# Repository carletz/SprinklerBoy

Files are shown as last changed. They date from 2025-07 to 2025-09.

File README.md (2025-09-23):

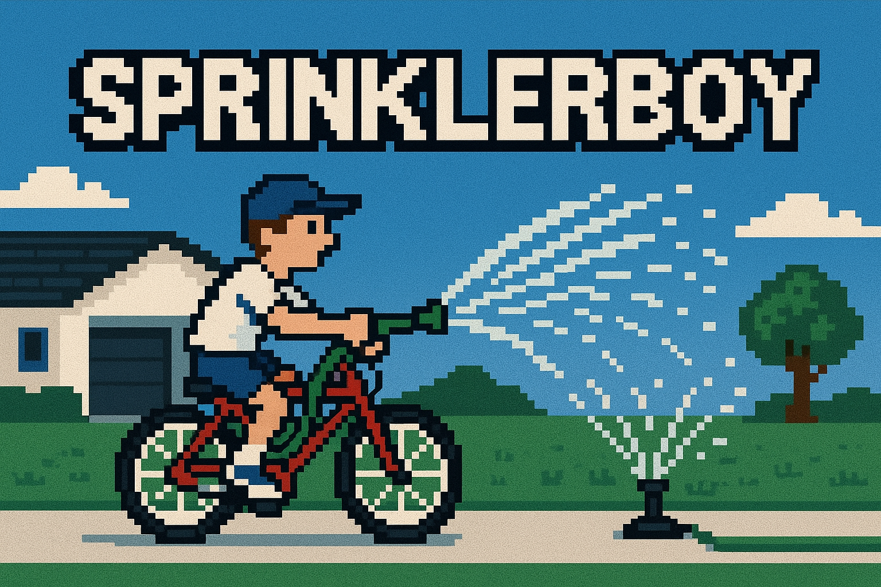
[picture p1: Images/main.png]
Render 1


# 🌿 SprinklerBoy – Take Full Control of Your Garden, the Smart Way

**SprinklerBoy** is your next-generation smart irrigation controller built around the powerful ESP32 and equipped with native Ethernet connectivity. Whether you're automating a home garden, greenhouse, or a professional irrigation system, SprinklerBoy delivers robust performance, high expandability, and complete control — right out of the box.

---

## 💡 Key Features

SprinklerBoy is a fully integrated, smart irrigation control system based on the **ESP32-WROOM-32UE** with native Ethernet **LAN8720A** support. Designed for reliable, flexible, and efficient irrigation, the project supports:

- Up to **8 AC-controlled sprinkler valves**
- Multiple **digital and analog inputs**
- **I2C-based expansion**
- **Robust surge protection**

### Main Hardware Features

- **ESP32 MCU**: Wi-Fi + Ethernet (LAN8720A PHY) with external antenna support  
- **8 Triac Outputs**: Control up to 8 AC sprinkler valves via opto-isolated TRIACs (MAC97A8)  
- **Input Protection**:  
  - Surge protection (SMBJ43CA)  
  - Flyback diodes (SS34)  
  - Fuses on both logic and power lines  
- **Multi-Input Capability**:  
  - 1 dry-contact input (e.g., rain sensor, external switches)  
  - 8 local physical push buttons  
  - 1 I2C analog keypad input (via ADS1115)  
  - I2C temperature and rain sensors  

### Communication Interfaces

- **Ethernet (LAN8720A)** with RJ45 magjack and status LEDs  
- **USB Type-C + CH340C** for programming and serial debug  
- **I2C bus** for additional peripherals and sensors  

### Power Supply

- Single **5V DC input** (external or USB-powered)  
- On-board **3.3V and 5V regulators** using LDO and switching converters (BL1117-33, XL1509)

### Modular Design

Four independent schematic blocks:

1. Controller Core (ESP32)  
2. Ethernet Interface  
3. Valve Output & Power Supply  
4. Input Interface Board  

> 🛠️ PCB ready: Designed in **EasyEDA** and optimized for **JLCPCB** assembly

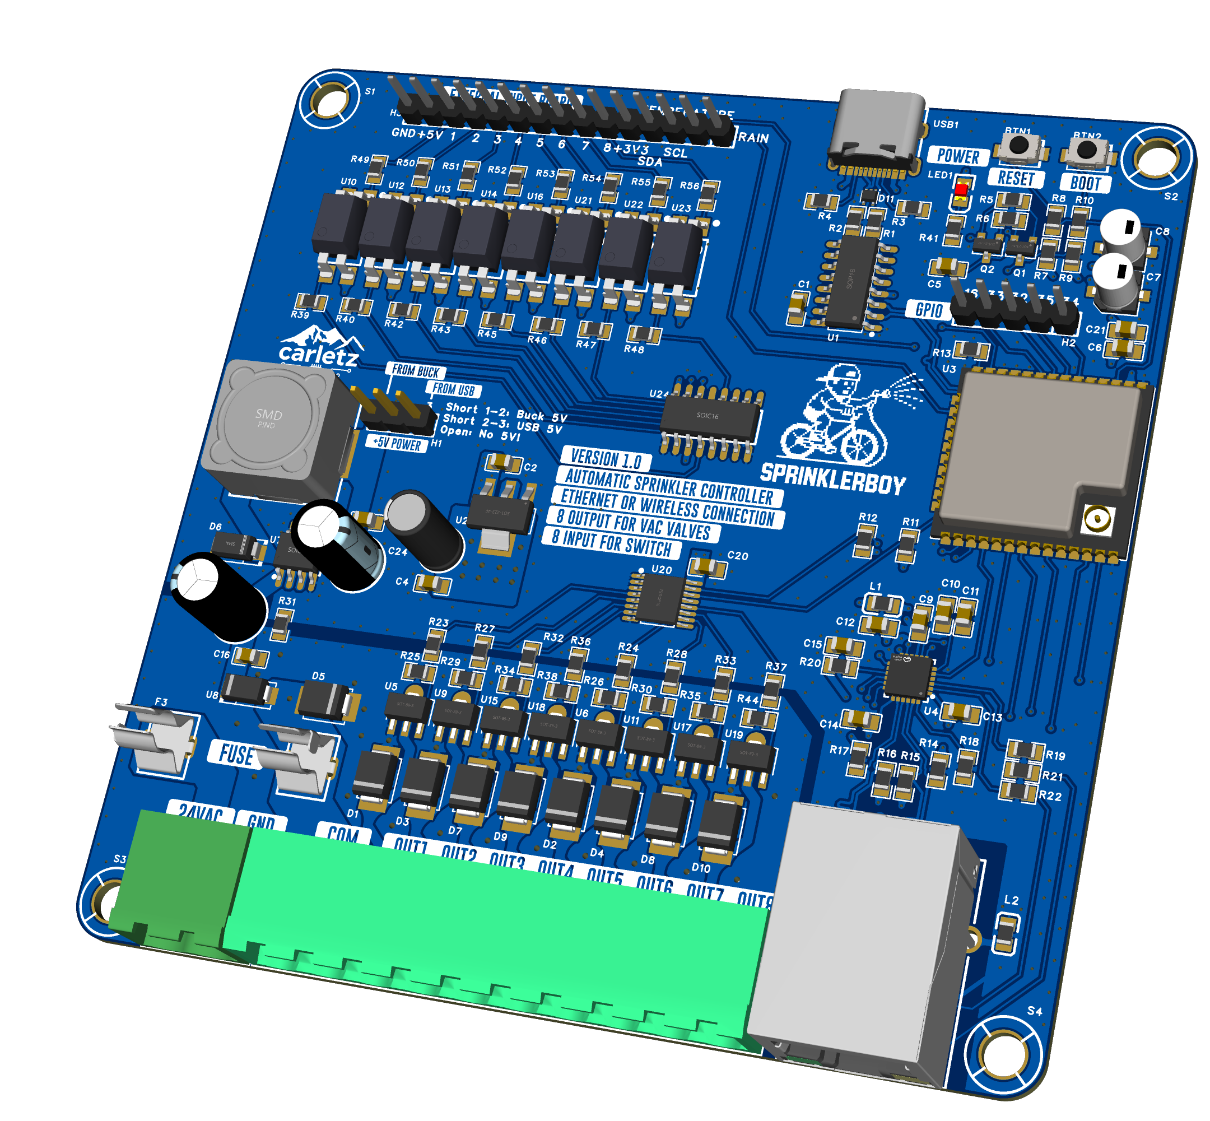
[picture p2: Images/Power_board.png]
Render 2


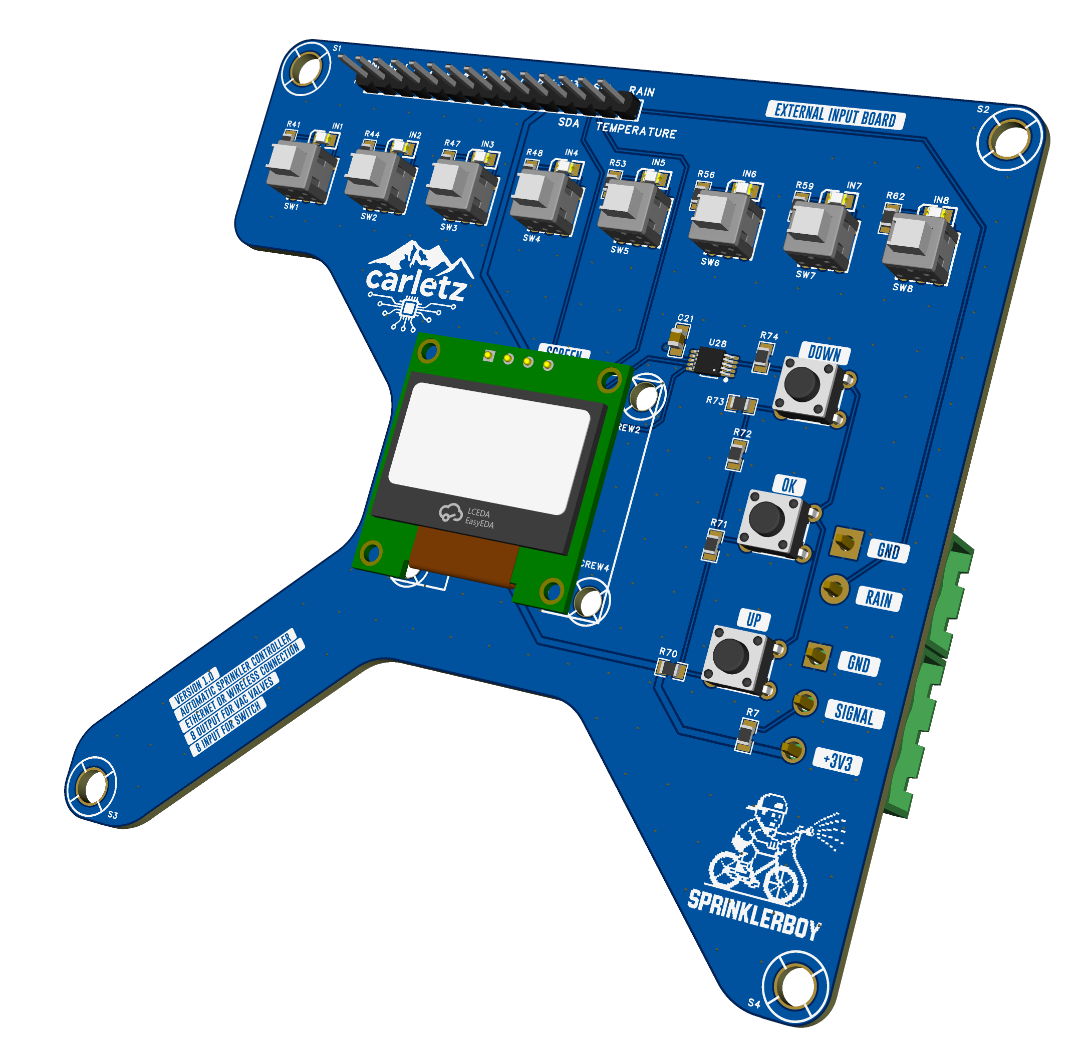
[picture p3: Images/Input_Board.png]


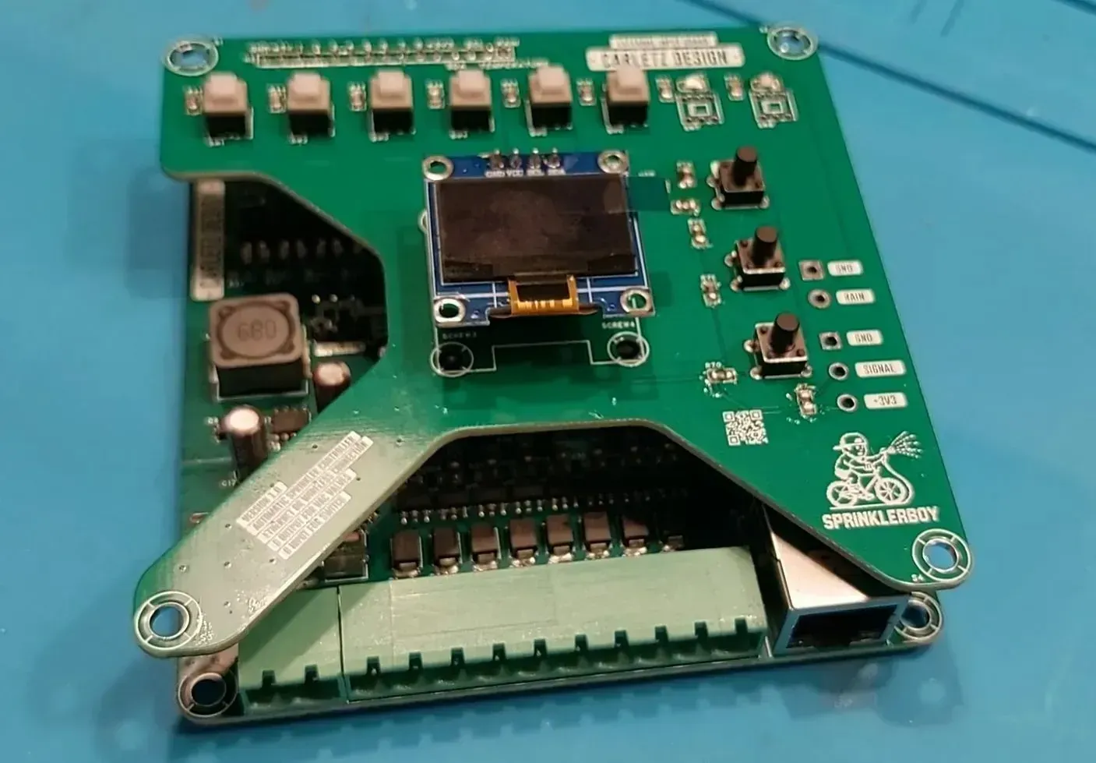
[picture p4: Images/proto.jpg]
Render 4


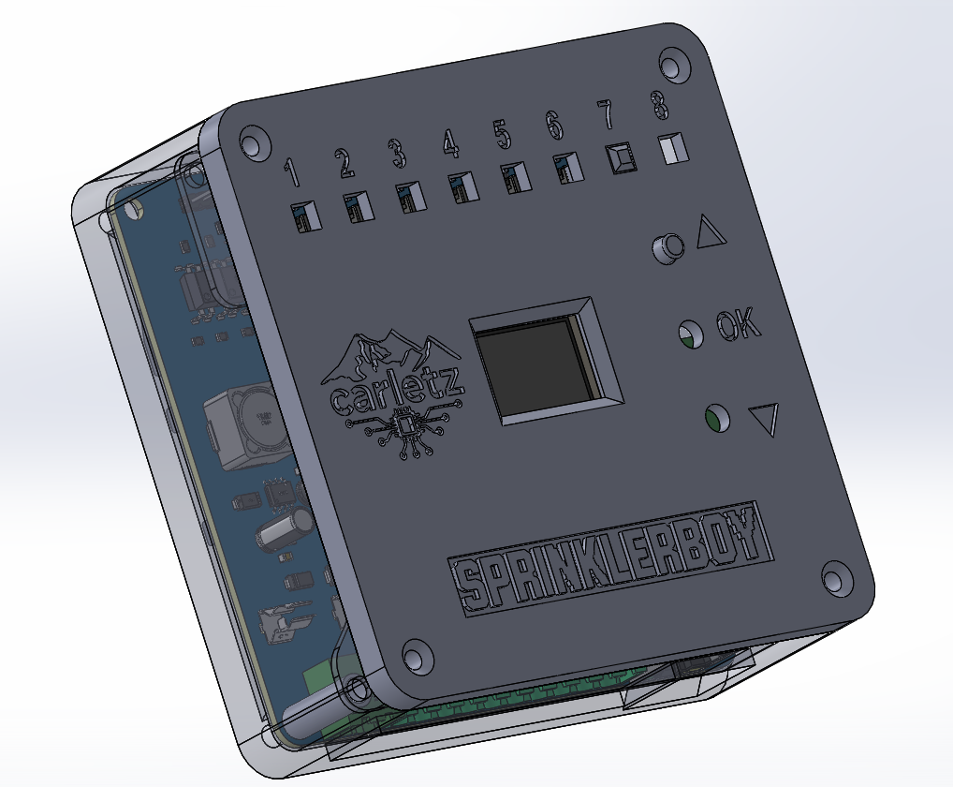
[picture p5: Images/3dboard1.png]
Render 5


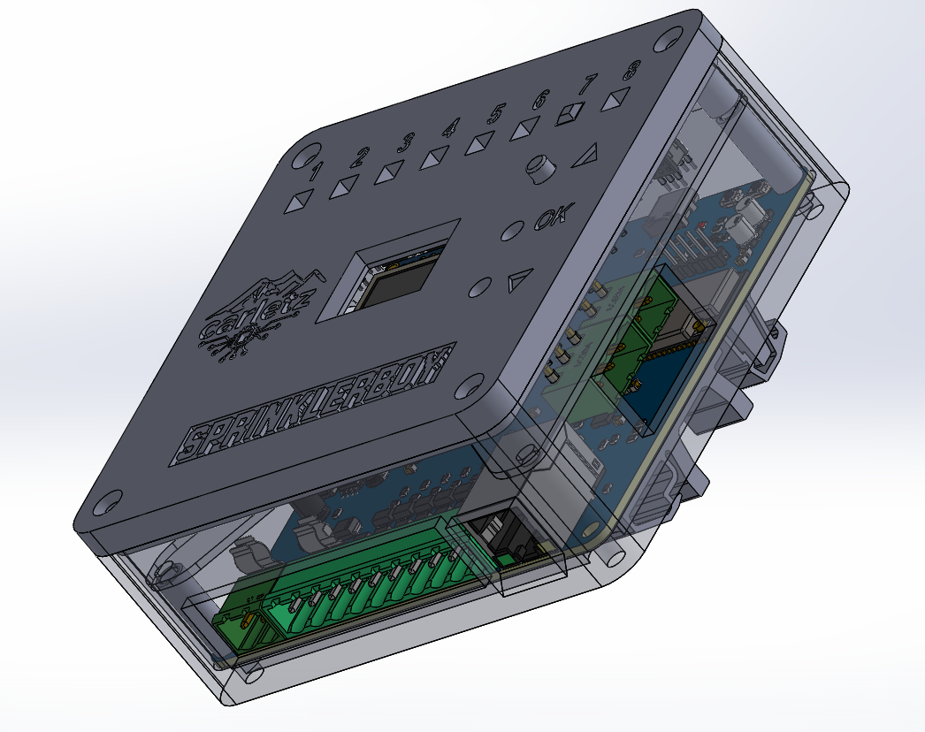
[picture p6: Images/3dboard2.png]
Render 6


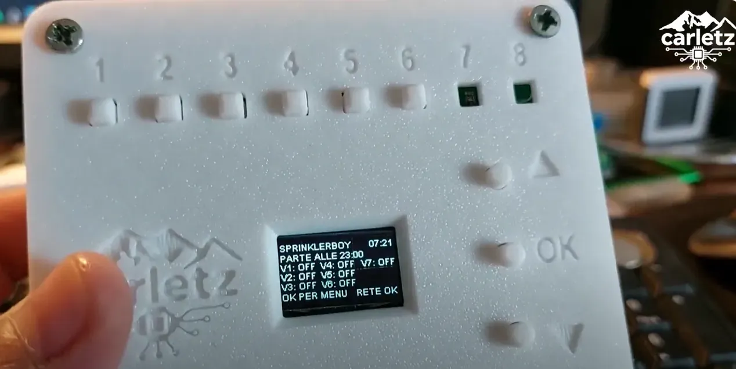
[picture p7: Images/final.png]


---

---
## 🎥 Construction Video

Watch the video (https://youtu.be/Xu3LNq0fTHU) 

---

## 🔧 Applications

- Home garden irrigation automation  
- Greenhouse or agricultural control systems  
- Integration with home automation platforms (via MQTT, HTTP, Modbus, etc.)

---

## ⚙️ Firmware Features – `sprinklerboy.yaml`

This **ESPHome-based** YAML configuration powers the SprinklerBoy smart irrigation controller, offering full integration with sensors, display, and networking.  
> The file given it's just an overall example, it have to be adapted to your needs.

---

## 🔌 Connectivity & Core

- ESP32 platform with:
  - Native Ethernet via `esp32_ethernet` using LAN8720  
  - Optional fallback Wi-Fi configuration  
- **MQTT Client**:
  - Publishes and subscribes to irrigation status, commands, schedules, and system variables  
  - Allows full control from platforms like **Home Assistant**, **OpenHAB**, or **Node-RED**

---

## 🌱 Irrigation Control

- **8 irrigation valves** controlled via GPIOs (mapped to hardware TRIACs)  
- **Automatic sequential irrigation**:
  - Configurable runtime per valve  
  - Optional skipping of disabled valves  
  - 5-second pause between valve changes  
- **Manual mode** via MQTT or physical button  
- **Weekly scheduler**:
  - Enable/disable irrigation per day (Mon–Sun)  
  - Each day configurable independently  

---

## 📟 User Interface

- **OLED Display** (SSD1306 128x64):
  - Real-time status updates (active valve, countdown, errors)  
  - Menu navigation using 3 physical buttons (UP, DOWN, OK)  
  - Inactivity timeout returns to standby screen showing:
    - Current time/date  
    - Connection status (ETH or fallback)  
    - Valve enable status summary  

### Menu System:

- Valve status toggle  
- Daily scheduling per valve  
- Irrigation enable/disable  
- Display mode toggle (active screen or standby)

---

## 🌧️ Sensor Inputs

- **Rain sensor** (digital, GPIO16):  
  When rain is detected, automatic irrigation is inhibited  

- **External temperature sensor** (via MQTT or physical):  
  Reserved for potential future logic (e.g., frost prevention)

---

## 🔘 Inputs

- 3 analog buttons via **ADS1115** (menu navigation)  
- 8 digital dry-contact inputs (opto-isolated):  
  - Usable for triggers, overrides, manual start, etc.

---

## 📤 MQTT Topics Overview

Includes topics for:

- Starting/stopping irrigation  
- Enabling/disabling individual valves  
- Scheduling per day  
- Reading back system status:
  - Active valve  
  - Remaining time  
  - Rain detection  
  - Connection status  
  - Errors  

---

## 🛡️ Safety & Logic

- Prevents irrigation when rain is detected  
- Watchdog logic to ensure no valve stays stuck  
- Auto-reset irrigation cycle in case of error  

---

## ⚠️ Disclaimer

> This project is provided for **educational purposes only**.

The author(s) of this repository **do not take any responsibility** for:

- Incorrect use of the design or schematics  
- Damage to equipment, persons, or property  
- Installation in unsafe or non-compliant environments  

Any implementation of this project in real-world systems should be done under the responsibility of a **qualified professional**, and in compliance with local regulations and safety standards.

By using this material, you acknowledge that it is offered **as-is**, **without warranty of any kind**, and you agree to use it **at your own risk**.

---

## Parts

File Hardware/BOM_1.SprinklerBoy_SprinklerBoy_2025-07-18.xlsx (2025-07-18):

No. | Quantity | Comment | Designator | Footprint | Value | Manufacturer Part | Manufacturer | Supplier Part | Supplier | LCSC Stock | LCSC Price | Primary Category | Secondary Category | Pin Count | JLCPCB Stock | JLCPCB Price | 3D Model Title | Device | Name | Unique ID | Convert to PCB | Add into BOM | Symbol | Layer | Mounting Style
1 | 2 | TS-1088-AR02016 | BTN1,BTN2 | SW-SMD_L3.9-W3.0-P4.45 |  | TS-1088-AR02016 | XUNPU(讯普) | C720477 | LCSC |  |  | Switches | Tactile Switches | 2 | 346433 | 0.0061 | SW-SMD_L3.9-W2.9-H2.0-LS4.8 | TS-1088-AR02016 | TS-1088-AR02016 | gge95_1,gge98_1 |  | yes |  | T | SMT
2 | 11 | 100nF | C1,C4,C11,C12,C13,C14,C15,C16,C19,C20,C21 | C0805 | 100nF | CL21B104KCFNNNE | SAMSUNG(三星) | C28233 | LCSC |  |  | Capacitors | Multilayer Ceramic Capacitors MLCC - SMD/SMT | 2 | 1168110 | 0.0009 | C0805_L2.0-W1.3-H1.3 | CL21B104KCFNNNE | 100nF | gge212,gge212_1,gge212_2,gge212_3,gge212_4,gge212_5,gge212_6,gge212_7,gge216,gge216_1,gge251 |  | yes |  | T | SMT
3 | 1 | 10uF | C2 | C0805 | 10uF | GRM21BR61H106KE43L | muRata(村田) | C440198 | LCSC |  |  | Capacitors | Multilayer Ceramic Capacitors MLCC - SMD/SMT | 2 | 1420512 | 0.0094 | C0805_L2.0-W1.3-H1.3 | GRM21BR61H106KE43L | 10uF | gge263 |  | yes |  | T | SMT
4 | 1 | 1uF | C5 | C0805 | 1uF | HHV0805R7105K101NSLJ | Chinocera(华瓷) | C22367837 | LCSC |  |  | Capacitors | Multilayer Ceramic Capacitors MLCC - SMD/SMT | 2 | 49911 | 0.0037 | C0805_L2.0-W1.3-H1.3 | HHV0805R7105K101NSLJ | 1uF | gge251_1 |  | yes |  | T | SMT
5 | 3 | 10uF | C6,C9,C10 | C0805 | 10uF | CL21A106KOQNNNE | SAMSUNG(三星) | C1713 | LCSC |  |  | Capacitors | Multilayer Ceramic Capacitors MLCC - SMD/SMT | 2 | 5303908 | 0.0013 | C0805_L2.0-W1.3-H1.3 | CL21A106KOQNNNE | 10uF | gge199,gge199_1,gge200 |  | yes |  | T | SMT
6 | 2 | 10uF | C7,C8 | CAP-SMD_BD4.0-L4.3-W4.3-LS5.1-FD | 10uF | VE-100M1ATR-0405 | lelon(立隆) | C249449 | LCSC |  |  | Capacitors | Aluminum Electrolytic Capacitors - SMD | 2 | 1 | 0.0083 | CAP-SMD_BD4.0-L4.3-W4.3-LS5.1-FD | VE-100M1ATR-0405 | 10uF | gge137_1,gge138_1 |  | yes |  | T | SMT
7 | 1 | 100uF | C22 | CAP-TH_BD5.0-P2.00-D0.5-FD-1 | 100uF | KM1A101M0507 | ROQANG(容强) | C2874000 | LCSC |  |  | Capacitors | Aluminum Electrolytic Capacitors - Leaded | 2 | 0 |  | CAP-TH_BD5.0-P2.00-D0.5-FD-1 | KM1A101M0507 | 100uF | gge304 |  | yes |  | T | DIP
8 | 2 | 100uF | C23,C24 | CAP-TH_BD6.3-P2.50-D1.0-FD | 100uF | GR107M050E12RR0VH4FP0 | CX(承兴) | C47891 | LCSC |  |  | Capacitors | Aluminum Electrolytic Capacitors - Leaded | 2 | 231035 | 0.005 | CAP-TH_BD6.3-P2.50-D1.0-FD | GR107M050E12RR0VH4FP0 | 100uF | gge305,gge306 |  | yes |  | T | DIP
9 | 1 | WJ2EDGRC-5.08-2P | CN1 | CONN-TH_2P-P5.08_WJ2EDGRC-5.08-2P |  | WJ2EDGRC-5.08-2P | KANGNEX(康奈克斯电气) | C3697 | LCSC |  |  | Connectors | Pluggable System Terminal Block | 2 | 22009 | 0.0053 | CONN-TH_2P-L12.0-W12.2-H8.3-P5.08 | WJ2EDGRC-5.08-2P | WJ2EDGRC-5.08-2P | gge35_1 |  | yes |  | T | DIP
10 | 1 | WJ2EDGRC-5.08-10P | CN2 | CONN-TH_10P-P5.08_WJ2EDGRC-5.08-10P |  | WJ2EDGRC-5.08-10P | KANGNEX(康奈克斯电气) | C28429 | LCSC |  |  | Connectors | Pluggable System Terminal Block | 10 | 126 | 0.0245 | CONN-TH_10P-P5.08_WJ2EDGRC-5.08-10P | WJ2EDGRC-5.08-10P | WJ2EDGRC-5.08-10P | gge312_1 |  | yes |  | T | DIP
11 | 9 | SMBJ43CA | D1,D2,D3,D4,D5,D7,D8,D9,D10 | SMB_L4.5-W3.6-LS5.3-BI |  | SMBJ43CA | GOODWORK(固得沃克) | C908858 | LCSC |  |  | TVS/Fuse/Board Level Protection | TVS | 2 | 8 | 0.0056 | SMB_L4.5-W3.6-LS5.3-RD | SMBJ43CA_C908858 | SMBJ43CA | gge2,gge2_1,gge5,gge5_1,gge8,gge8_1,gge11,gge11_1,gge36 |  | yes |  | T | SMT
12 | 1 | SS34 | D6 | SMA_L4.3-W2.5-LS5.0-RD |  | SS34 | TWGMC(台湾迪嘉) | C727060 | LCSC |  |  | Diodes | Schottky Barrier Diodes (SBD) | 2 | 274280 | 0.0037 | SMA_L4.3-W2.5-LS5.0-RD-1 | SS34_C727060 | SS34 | gge44 |  | yes |  | T | SMT
13 | 1 | TPD2E2U06DRLR | D11 | SOT-553-5_L1.6-W1.2-P0.50-LS1.6-TL-1 |  | TPD2E2U06DRLR | TI(德州仪器) | C1972959 | LCSC |  |  | Circuit Protection | ESD and Surge Protection (TVS/ESD) | 5 | 5981 | 0.0373 | SOT-553-5_L1.6-W1.2-P0.50-LS1.6-TL-1 | TPD2E2U06DRLR | TPD2E2U06DRLR | gge302 |  | yes |  | T | SMT
14 | 2 | 5x20 环保 保险管夹/座 | F2,F3 | FUSE-TH_5X20RHOSFUSECLIP-SEAT |  | 5x20 环保 保险管夹/座 | xcfuse(旭程) | C3130 | LCSC |  |  | TVS/Fuse/Board Level Protection | Fuse Holders | 2 | 52537 | 0.0029 | FUSE-TH_5X20 | 5x20 环保 保险管夹/座 | 5x20 环保 保险管夹/座 | gge33,gge34 |  | yes |  | T | DIP
15 | 1 | 77311-102-03LF | H1 | HDR-TH_3P-P2.54-V-M-1 |  | 77311-102-03LF | Amphenol | C180248 | LCSC |  |  | Connectors | Pin Headers | 3 | 4854 | 0.0256 | HDR-M-2.54_1x3 | 77311-102-03LF | 77311-102-03LF | UNIQUEH7 |  | yes |  | T | DIP
16 | 1 | HDR-M_2.54_1x5P | H2 | HDR-TH_5P-P2.54-V-M |  |  |  |  |  | 1334700 | 0.0057 | Connectors | Pin Headers | 5 |  |  | HDR-TH_5P-P2.54-M-LI-1X5P | HDR-M_2.54_1x5P |  | gge298 |  | yes |  | T | DIP
17 | 1 | HDR-M_2.54_1x15P | H3 | HDR-TH_15P-P2.54-V-M |  |  |  |  |  | 1334700 | 0.0057 | Connectors | Pin Headers | 15 |  |  | HDR-TH_15P-P2.54-M-LI-1X15P | HDR-M_2.54_1x15P |  | gge303 |  | yes |  | T | DIP
18 | 1 | HR911105A | J1 | RJ45-TH_HR911105A |  | HR911105A | HANRUN(汉仁) | C12074 | LCSC |  |  | Connectors | Ethernet Connectors/Modular Connectors (RJ45 RJ11) | 14 | 87630 | 0.2073 | RJ45-TH_P1HR911105A | HR911105A_C12074 | HR911105A | gge127_1 |  | yes |  | T | DIP
19 | 1 | BLM21PG220SN1D | L1 | L0805 |  | BLM21PG220SN1D | muRata(村田) | C88993 | LCSC |  |  | Filters | Ferrite Beads | 2 | 31886 | 0.0024 | R0805_L2.0-W1.3-H0.6 | BLM21PG220SN1D | BLM21PG220SN1D | gge132 |  | yes |  | T | SMT
20 | 1 | HCB2012KF-121T50 | L2 | L0805 |  | HCB2012KF-121T50 | TAI-TECH(台庆) | C304323 | LCSC |  |  | Filters | Ferrite Beads | 2 | 5086 | 0.0011 | R0805_L2.0-W1.3-H0.6 | HCB2012KF-121T50 | HCB2012KF-121T50 | gge242 |  | yes |  | T | SMT
21 | 1 | 68uH | L3 | IND-SMD_L12.3-W12.3_SMDRI127 | 68uH | SMDRI127-680MT | SXN(顺翔诺) | C9907 | LCSC |  |  | Inductors/Coils/Transformers | Power Inductors | 2 | 26241 | 0.0288 | SMD-PIND_L12.5-W12.5-H8.0 | SMDRI127-680MT | 68uH | gge45 |  | yes |  | T | SMT
22 | 1 | XL-2012SURC | LED1 | LED0805-R-RD |  | XL-2012SURC | XINGLIGHT(成兴光) | C965812 | LCSC |  |  | Optoelectronics | LED Indication - Discrete | 2 | 382647 | 0.0008 | LED0805-RD_RED_XL-2012SURC-FJ | XL-2012SURC | XL-2012SURC | gge156_10 |  | yes |  | T | SMT
23 | 2 | SS8050 | Q1,Q2 | SOT-23-3_L2.9-W1.3-P1.90-LS2.4-BR |  | SS8050 | JSMSEMI(杰盛微) | C916392 | LCSC |  |  | Transistors/Thyristors | Bipolar (BJT) | 3 | 814688 | 0.0011 | SOT-23-3P_L2.9-W1.3-H1.0-LS2.4-P0.95 | SS8050_C916392 | SS8050 | gge143,gge144 |  | yes |  | T | SMT
24 | 2 | 10Ω | R1,R2 | R0805_NEW | 10Ω | 0805W8F100JT5E | UNI-ROYAL(厚声) | C17415 | LCSC |  |  | Resistors | Chip Resistor - Surface Mount | 2 | 3278979 | 0.0003 | R0805_L2.0-W1.3-H0.6 | 0805W8F100JT5E | 10Ω | gge250,gge250_1 |  | yes |  | T | SMT
25 | 2 | 5.1kΩ | R3,R4 | R0805 | 5.1kΩ | RC0805FR-075K1L | YAGEO(国巨) | C84375 | LCSC |  |  | Resistors | Chip Resistor - Surface Mount | 2 | 100328 | 0.0003 | R0805_L2.0-W1.3-H0.6 | RC0805FR-075K1L | 5.1kΩ | gge300,gge301 |  | yes |  | T | SMT
26 | 2 | 12kΩ | R5,R6 | R0805 | 12kΩ | 0805W8J0123T5E | UNI-ROYAL(厚声) | C25616 | LCSC |  |  | Resistors | Chip Resistor - Surface Mount | 2 | 15966 | 0.0002 | R0805_L2.0-W1.3-H0.6 | 0805W8J0123T5E | 12kΩ | gge261,gge262 |  | yes |  | T | SMT
27 | 15 | 10kΩ | R7,R9,R11,R12,R13,R19,R20,R25,R26,R29,R30,R34,R35,R38,R44 | R0805 | 10kΩ | RC0805FR-7W10KL | YAGEO(国巨) | C17414 | LCSC |  |  | Resistors | Chip Resistor - Surface Mount | 2 | 12292545 | 0.0003 | R0805_L2.0-W1.3-H0.6 | RC0805FR-7W10KL | 10kΩ | gge204,gge204_1,gge204_5,gge204_6,gge204_7,gge204_8,gge204_9,gge204_10,gge204_11,gge204_12,gge221,gge221_1,gge225,gge225_1,gge225_2 |  | yes |  | T | SMT
28 | 2 | 100Ω | R8,R10 | R0805 | 100Ω | AC0805FR-7W100RL | YAGEO(国巨) | C727982 | LCSC |  |  | Resistors | Chip Resistor - Surface Mount | 2 | 3590 | 0.0012 | R0805_L2.0-W1.3-H0.6 | AC0805FR-7W100RL | 100Ω | gge252,gge253 |  | yes |  | T | SMT
29 | 4 | 49.9Ω | R14,R15,R16,R17 | R0805 | 49.9Ω | 0805W8F499JT5E | UNI-ROYAL(厚声) | C17720 | LCSC |  |  | Resistors | Chip Resistor - Surface Mount | 2 | 207272 | 0.0003 | R0805_L2.0-W1.3-H0.6 | 0805W8F499JT5E | 49.9Ω | gge238,gge238_1,gge238_2,gge238_3 |  | yes |  | T | SMT
30 | 1 | 12.1kΩ | R18 | R0805 | 12.1kΩ | 0805W8F1212T5E | UNI-ROYAL(厚声) | C17431 | LCSC |  |  | Resistors | Chip Resistor - Surface Mount | 2 | 9363 | 0.0003 | R0805_L2.0-W1.3-H0.6 | 0805W8F1212T5E | 12.1kΩ | gge254 |  | yes |  | T | SMT
31 | 2 | 510Ω | R21,R22 | R0805 | 510Ω | FRC0805J511 TS | FOJAN(富捷) | C2907333 | LCSC |  |  | Resistors | Chip Resistor - Surface Mount | 2 | 172084 | 0.0002 | R0805_L2.0-W1.3-H0.6 | FRC0805J511 TS | 510Ω | gge235,gge235_1 |  | yes |  | T | SMT
32 | 8 | 390Ω | R23,R24,R27,R28,R32,R33,R36,R37 | R0805 | 390Ω | 0805W8J0391T5E | UNI-ROYAL(厚声) | C25310 | LCSC |  |  | Resistors | Chip Resistor - Surface Mount | 2 | 22806 | 0.0003 | R0805_L2.0-W1.3-H0.6 | 0805W8J0391T5E | 390Ω | gge255,gge255_1,gge256,gge256_1,gge257,gge257_1,gge258,gge258_1 |  | yes |  | T | SMT
33 | 1 | 0Ω | R31 | R0805 | 0Ω | 0805W8F0000T5E | UNI-ROYAL(厚声) | C17477 | LCSC |  |  | Resistors | Chip Resistor - Surface Mount | 2 | 7785054 | 0.0003 | R0805_L2.0-W1.3-H0.6 | 0805W8F0000T5E_C17477 | 0Ω | gge240 |  | yes |  | T | SMT
34 | 8 | 1.43kΩ | R39,R40,R42,R43,R45,R46,R47,R48 | R0805 | 1.43kΩ | FRC0805F1431TS | FOJAN | C2933316 | LCSC |  |  | Resistors | Chip Resistor - Surface Mount | 2 | 5827 | 0.0003 | R0805_L2.0-W1.3-H0.6 | FRC0805F1431TS | 1.43kΩ | gge265,gge266,gge267,gge268,gge269,gge270,gge289,gge293 |  | yes |  | T | SMT
35 | 1 | 1kΩ | R41 | R0805 | 1kΩ | 0805W8F1001T5E | UNI-ROYAL(厚声) | C17513 | LCSC |  |  | Resistors | Chip Resistor - Surface Mount | 2 | 7426224 | 0.0003 | R0805_L2.0-W1.3-H0.6 | 0805W8F1001T5E | 1kΩ | gge254_1 |  | yes |  | T | SMT
36 | 8 | 1.33kΩ | R49,R50,R51,R52,R53,R54,R55,R56 | R0805 | 1.33kΩ | RC0805FR-071K33L | YAGEO(国巨) | C276298 | LCSC |  |  | Resistors | Chip Resistor - Surface Mount | 2 | 1749 | 0.0003 | R0805_L2.0-W1.3-H0.6 | RC0805FR-071K33L | 1.33kΩ | gge271,gge272,gge273,gge274,gge275,gge276,gge292,gge296 |  | yes |  | T | SMT
37 | 9 | PCB-SGAP | SP1,SP2,SP3,SP4,SP5,SP6,SP7,SP8,SP9 | AIR-GAP |  |  |  |  |  | 1334700 | 0.0057 |  |  | 2 |  |  |  | PCB-SGAP | PCB-SGAP | gge3,gge3_1,gge6,gge6_1,gge9,gge9_1,gge12,gge12_1,gge37 |  | yes |  | B | SMT
38 | 1 | CH340C | U1 | SOP-16_L10.0-W3.9-P1.27-LS6.0-BL |  | CH340C | WCH(南京沁恒) | C84681 | LCSC |  |  | Interface | USB Converters | 16 | 11967 | 0.0744 | SOP-16_L9.9-W3.9-H1.5-LS6.0-P1.27 | CH340C | CH340C | gge140 |  | yes |  | T | SMT
39 | 1 | BL1117-33CX | U2 | SOT-223-4_L6.5-W3.5-P2.30-LS7.0-BR |  | BL1117-33CX | BL(上海贝岭) | C5400 | LCSC |  |  | Power Management (PMIC) | Voltage Regulators - Linear, Low Drop Out (LDO) Regulators | 4 | 58592 | 0.0071 | SOT-223-4P_L6.5-W3.5-H1.6-LS7.0-P2.30 | BL1117-33CX | BL1117-33CX | gge46 |  | yes |  | T | SMT
40 | 1 | ESP32-WROOM-32UE-N8 | U3 | WIFI-SMD_ESP32-WROOM-32UE |  | ESP32-WROOM-32UE-N8 | ESPRESSIF(乐鑫) | C701345 | LCSC |  |  | IoT/Communication Modules | WiFi Modules | 47 | 2177 | 0.524 | WIFI-SMD_L19.2-18.0-H3.2-ESP32-WROOM-32UE | ESP32-WROOM-32UE-N8 | ESP32-WROOM-32UE-N8 | gge134 |  | yes |  | T | SMT
41 | 1 | LAN8720A-CP-TR-ABC | U4 | QFN-24_L4.0-W4.0-P0.50-TL-EP2.5 |  | LAN8720A-CP-TR-ABC | MICROCHIP(美国微芯) | C621419 | LCSC |  |  | Interface | Ethernet Transceivers | 25 | 1462 | 0.1477 | VFQFN-24_L4.0-W4.0-P0.50-TL-EP2.1 | LAN8720A-CP-TR-ABC | LAN8720A-CP-TR-ABC | gge131 |  | yes |  | T | SMT
42 | 8 | MAC97A8 | U5,U6,U9,U11,U15,U17,U18,U19 | SOT-89-3_L4.5-W2.5-P1.50-LS4.2-BR |  | MAC97A8 | MSKSEMI(美森科) | C5140027 | LCSC |  |  | Triode/MOS Tube/Transistor | TRIACs | 3 | 440 | 0.0108 | SOT-89-3_L4.3-W2.5-H1.6-LS4.1-P1.50 | MAC97A8_1 | MAC97A8 | gge1,gge1_1,gge4,gge4_1,gge7,gge7_1,gge10,gge10_1 |  | yes |  | T | SMT
43 | 1 | XL1509-5.0E1 | U7 | SOIC-8_L5.0-W4.0-P1.27-LS6.0-BL |  | XL1509-5.0E1 | XLSEMI(芯龙) | C61063 | LCSC |  |  | Power Supply Chip | DC-DC Converters | 8 | 428775 | 0.0317 | SOIC-8_L4.9-W3.9-H1.7-LS6.0-P1.27 | XL1509-5.0E1 | XL1509-5.0E1 | gge40 |  | yes |  | T | SMT
44 | 1 | M7 | U8 | SMA_L4.5-W2.7-LS5.1-RD |  | M7 | MSKSEMI(美森科) | C2902910 | LCSC |  |  | Diodes | Diodes - General Purpose | 2 | 1130935 | 0.0008 | SMA_L4.5-W2.7-LS5.1-RD | M7_C2902910 | M7 | gge43 |  | yes |  | T | SMT
45 | 8 | PC817AS | U10,U12,U13,U14,U16,U21,U22,U23 | SOP-4_L6.4-W4.6-P2.54-LS10.2-BL |  | PC817AS | AOTE(奥特) | C22375537 | LCSC |  |  | Optoisolators | Transistor, Photovoltaic Output Optoisolators | 4 | 1860 | 0.0065 | SOP-4_L6.5-W4.6-H4.5-P2.54-LS10.2-TL | PC817AS | PC817AS | gge147,gge152,gge156,gge160,gge164,gge168,gge168_1,gge168_2 |  | yes |  | T | SMT
46 | 1 | PCA9554APW,118 | U20 | TSSOP-16_L5.0-W4.4-P0.65-LS6.4-BL |  | PCA9554APW,118 | NXP(恩智浦) | C86803 | LCSC |  |  | Communication Interface Chip/UART/485/232 | I/O Expanders | 16 | 3050 | 0.1158 | TSSOP-16_L5.0-W4.4-H1.0-LS6.4-P0.65 | PCA9554APW,118 | PCA9554APW,118 | gge53 |  | yes |  | T | SMT
47 | 1 | PCF8574M/TR | U24 | SOIC-16_L9.9-W3.9-P1.27-LS6.0-BL-1 |  | PCF8574M/TR | HGSEMI(华冠) | C5310792 | LCSC |  |  | Interface | I/O Expanders | 16 | 1197 | 0.1035 | SOIC-16_L9.9-W3.9-H1.8-LS6.0-P1.27-EP13 | PCF8574M/TR | PCF8574M/TR | gge144_1 |  | yes |  | T | SMT
48 | 1 | TYPE-C 16PIN 2MD(073) | USB1 | USB-C-SMD_TYPE-C-6PIN-2MD-073 |  | TYPE-C 16PIN 2MD(073) | SHOU HAN(首韩) | C2765186 | LCSC |  |  | Connectors | USB Connectors | 16 | 444139 | 0.0081 | USB-C-SMD_TYPE-C-6PIN-2MD-073 | TYPE-C 16PIN 2MD(073) | TYPE-C 16PIN 2MD(073) | gge130_1 |  | yes |  | T | DIP

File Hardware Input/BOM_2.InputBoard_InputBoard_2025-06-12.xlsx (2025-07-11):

No. | Quantity | Comment | Designator | Footprint | Value | Manufacturer Part | Manufacturer | Supplier Part | Supplier | LCSC Stock | LCSC Price | Primary Category | Secondary Category | Pin Count | JLCPCB Stock | JLCPCB Price | 3D Model Title | Device | Name | Unique ID | Convert to PCB | Add into BOM | Symbol | Layer | Mounting Style
1 | 3 | KH-6X6X8H-TJ | ((DOWN)),((OK)),((UP)) | SW-TH_4P-L6.0-W6.0-P4.50-LS6.5 |  | KH-6X6X8H-TJ | kinghelm(金航标) | C2837518 | LCSC |  |  | Key/Switch | Tactile Switches | 4 | 4729 | 0.0021 | SW-TH_4P-L6.0-W6.0-H5.0-LS6.5-P4.50 | KH-6X6X8H-TJ | KH-6X6X8H-TJ | gge35_1,gge36_1,gge38 |  | yes |  | T | Straight
2 | 1 | 1uF | C21 | C0805 | 1uF | HHV0805R7105K101NSLJ | Chinocera(华瓷) | C22367837 | LCSC |  |  | Capacitors | Multilayer Ceramic Capacitors MLCC - SMD/SMT | 2 | 46397 | 0.0038 | C0805_L2.0-W1.3-H1.3 | HHV0805R7105K101NSLJ | 1uF | gge251_2 |  | yes |  | T
3 | 1 | WJ2EDGRC-5.08-3P | CN1 | CONN-TH_3P-P5.08_WJ2EDGRC-5.08-3P |  | WJ2EDGRC-5.08-3P | KANGNEX(康奈克斯电气) | C8377 | LCSC |  |  | Connectors | Pluggable System Terminal Block | 3 | 6038 | 0.0079 | CONN-TH_WJ5.08-WI-3P-4 | WJ2EDGRC-5.08-3P_C8377 | WJ2EDGRC-5.08-3P | gge50_1 |  | yes |  | B | Bend
4 | 1 | WJ2EDGRC-5.08-2P | CN2 | CONN-TH_2P-P5.08_WJ2EDGRC-5.08-2P |  | WJ2EDGRC-5.08-2P | KANGNEX(康奈克斯电气) | C3697 | LCSC |  |  | Connectors | Pluggable System Terminal Block | 2 | 16690 | 0.0053 | CONN-TH_2P-L12.0-W12.2-H8.3-P5.08 | WJ2EDGRC-5.08-2P | WJ2EDGRC-5.08-2P | gge35_2 |  | yes |  | B | Bend
5 | 1 | HDR-M_2.54_1x15P | H3 | HDR-TH_15P-P2.54-V-M |  |  |  |  |  | 690 | 0.1743 | Connectors | Pin Headers | 15 |  |  | HDR-TH_15P-P2.54-M-LI-1X15P | HDR-M_2.54_1x15P |  | gge303_1 |  | yes |  | T
6 | 8 | XL-2012SURC | IN1,IN2,IN3,IN4,IN5,IN6,IN7,IN8 | LED0805-R-RD |  | XL-2012SURC | XINGLIGHT(成兴光) | C965812 | LCSC |  |  | Optoelectronics | LED Indication - Discrete | 2 | 1044465 | 0.0008 | LED0805-RD | XL-2012SURC | XL-2012SURC | gge156_1,gge156_2,gge156_3,gge156_4,gge156_5,gge156_6,gge156_7,gge156_8 |  | yes |  | T
7 | 1 | 4.7kΩ | R7 | R0805 | 4.7kΩ | 0805W8F4701T5E | UNI-ROYAL(厚声) | C17673 | LCSC |  |  | Resistors | Chip Resistor - Surface Mount | 2 | 8008773 | 0.0003 | R0805_L2.0-W1.3-H0.6 | 0805W8F4701T5E | 4.7kΩ | gge246 |  | yes |  | T
8 | 8 | 220Ω | R41,R44,R47,R48,R53,R56,R59,R62 | R0805 | 220Ω | 0805W8F2200T5E | UNI-ROYAL(厚声) | C17557 | LCSC |  |  | Resistors | Chip Resistor - Surface Mount | 2 | 816371 | 0.0003 | R0805_L2.0-W1.3-H0.6 | 0805W8F2200T5E | 220Ω | gge277,gge278_1,gge279_2,gge279_3,gge281,gge282,gge291,gge295 |  | yes |  | T
9 | 4 | 1kΩ | R70,R71,R72,R73 | R0805 | 1kΩ | 0805W8F1001T5E | UNI-ROYAL(厚声) | C17513 | LCSC |  |  | Resistors | Chip Resistor - Surface Mount | 2 | 10341441 | 0.0003 | R0805_L2.0-W1.3-H0.6 | 0805W8F1001T5E | 1kΩ | gge305,gge306,gge307,gge308 |  | yes |  | T
10 | 1 | 1MΩ | R74 | R0805 | 1MΩ | 0805W8F1004T5E | UNI-ROYAL(厚声) | C17514 | LCSC |  |  | Resistors | Chip Resistor - Surface Mount | 2 | 1835631 | 0.0003 | R0805_L2.0-W1.3-H0.6 | 0805W8F1004T5E | 1MΩ | gge309 |  | yes |  | T
11 | 4 | Screw-Hole-M3 | SCREW1,SCREW2,SCREW3,SCREW4 | Screw-Hole-M3 |  |  |  |  |  | 690 | 0.1743 |  |  | 1 |  |  |  | Screw-Hole-M3 |  | $1,$2,$3,$4 |  | yes |  | T
12 | 8 | 5.8 ZSPT | SW1,SW2,SW3,SW4,SW5,SW6,SW7,SW8 | SW-TH_5.8ZSPT |  | 5.8 ZSPT | SHOU HAN(首韩) | C2681588 | LCSC |  |  | Switches | Pushbutton Switches | 6 | 15481 | 0.0128 | SW-TH_5.8ZSPT | 5.8 ZSPT | 5.8 ZSPT | gge278,gge278_2,gge278_3,gge278_4,gge278_5,gge278_6,gge278_7,gge278_8 |  | yes |  | T
13 | 1 | HS96L03W2C03 | U27 | OLED-TH_L27.8-W27.2-P2.54_C9900033791 |  | HS96L03W2C03 | HS(汉昇) | C5248080 | LCSC |  |  | Displays | OLED Display | 4 | 95 | 0.2816 | OLED-TH_L27.8-W27.2-P2.54_C9900033791 | HS96L03W2C03 | HS96L03W2C03 | gge304 |  | yes |  | T
14 | 1 | ADS1115IDGSR | U28 | MSOP-10_L3.0-W3.0-P0.50-LS5.0-BL |  | ADS1115IDGSR | TI(德州仪器) | C37593 | LCSC |  |  | Data Acquisition | Analog to Digital Converters (ADC) | 10 | 10239 | 0.1363 | MSOP-10_L3.0-W3.0-H1.1-LS5.0-P0.50 | ADS1115IDGSR | ADS1115IDGSR | gge190 |  | yes |  | T

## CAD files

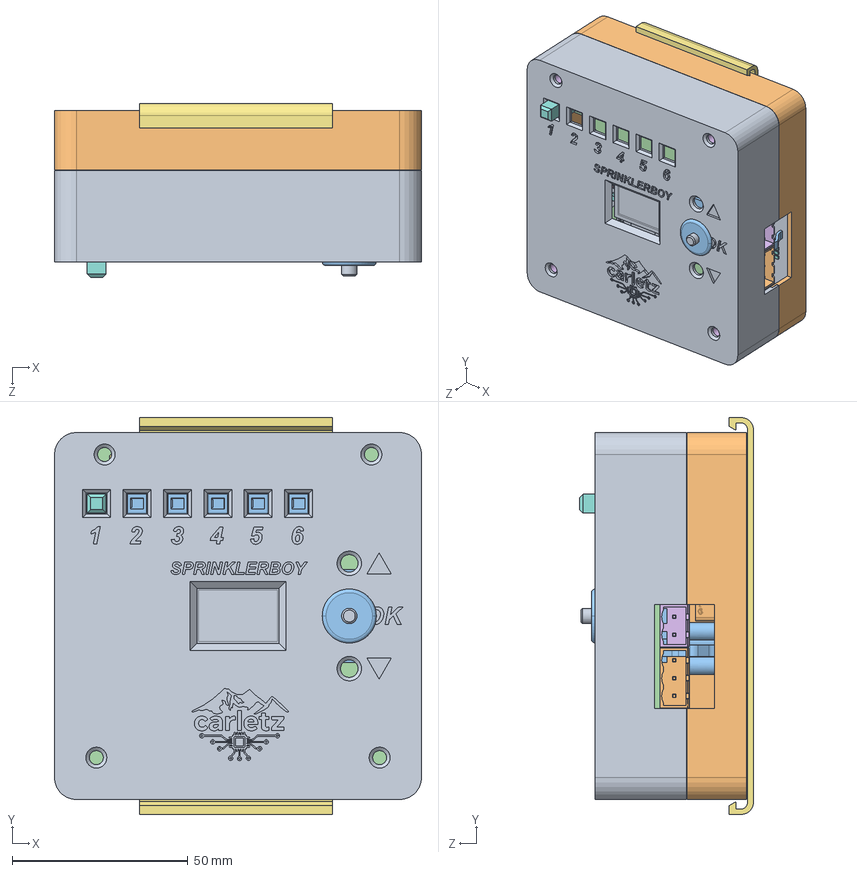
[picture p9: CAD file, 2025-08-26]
3D Model/SBScatola.SLDASM
104.6 x 113.1 x 49.6 mm
CAP-TH_BD5.0-P2.00-D0.8-FD~CAP-TH_BD5.0-P2.00-D0.5-FD-A~FMY4.step x 3
SMA_L4.3-W2.5-LS5.0-RD~SMA_L4.3-W2.5-LS5.0-RD-1~FMY4.step
FUSE-TH_5X20RHOSFUSECLIP-SEAT~FUSE-TH_5X20~FMY4.step x 2
HDR-TH_3P-P2.54-V-M-1~HDR-M-2.54_1x3~FMY4.step
L0805~R0805_L2.0-W1.3-H0.6~FMY4.step x 2
R0805_NEW~R0805_L2.0-W1.3-H0.6~FMY4.step x 56
RJ45-TH_HR911105A~RJ45-TH_HR911105A~FMY4.step
IND-SMD_L12.3-W12.3_SMDRI127~SMD-PIND_L12.5-W12.5-H8.0~FMY4.step
SOT-23-3_L2.9-W1.3-P1.90-LS2.4-BR~SOT-23-3P_L2.9-W1.3-H1.0-LS2.4-P0.95~FMY4.step x 2
WIFI-SMD_ESP32-WROOM-32UE~WIFI-SMD_L19.2-18.0-H3.2-ESP32-WROOM-32UE~FMY4.step
QFN-24_L4.0-W4.0-P0.50-TL-EP2.5~VFQFN-24_L4.0-W4.0-P0.50-TL-EP2.1~FMY4.step
SOP-4_L6.4-W4.6-P2.54-LS10.2-BL~SOP-4_L6.5-W4.6-H4.5-P2.54-LS10.2-TL~FMY4.step x 8
SOT-223-4_L6.5-W3.5-P2.30-LS7.0-BR~SOT-223-4P_L6.5-W3.5-H1.6-LS7.0-P2.30~FMY4.step
SMA_L4.5-W2.7-LS5.1-RD~SMA_L4.5-W2.7-LS5.1-RD~FMY4.step
TSSOP-16_L5.0-W4.4-P0.65-LS6.4-BL~TSSOP-16_L5.0-W4.4-H1.0-LS6.4-P0.65~FMY4.step
SOIC-8_L5.0-W4.0-P1.27-LS6.0-BL~SOIC-8_L4.9-W3.9-H1.7-LS6.0-P1.27~FMY4.step
SOT-89-3_L4.5-W2.5-P1.50-LS4.2-BR~SOT-89-3_L4.3-W2.5-H1.6-LS4.1-P1.50~FMY4.step x 8
LED0805-R-RD~LED0805-RD_RED_XL-2012SURC-FJ~FMY4.step
C0805~C0805_L2.0-W1.3-H1.3~FMY4.step x 16
CAP-SMD_BD4.0-L4.3-W4.3-LS5.1-FD~CAP-SMD_BD4.0-L4.3-W4.3-LS5.1-FD~FMY4.step x 2
HDR-TH_5P-P2.54-V-M~HDR-TH_5P-P2.54-M-LI-1X5P~FMY4.step
CONN-TH_10P-P5.08_WJ2EDGRC-5.08-10P~CONN-TH_10P-P5.08_WJ2EDGRC-5.08-10P~FMY4.step
USB-C-SMD_TYPE-C-6PIN-2MD-073~USB-C-SMD_TYPE-C-6PIN-2MD-073~FMY4.step
CONN-TH_2P-P5.08_WJ2EDGRC-5.08-2P~CONN-TH_2P-L12.0-W12.2-H8.3-P5.08~FMY4.step
SW-SMD_L3.9-W3.0-P4.45~SW-SMD_L3.9-W2.9-H2.0-LS4.8~FMY4.step x 2
SOT-553-5_L1.6-W1.2-P0.50-LS1.6-TL-1~SOT-553-5_L1.6-W1.2-P0.50-LS1.6-TL-1~FMY4.step
HDR-TH_15P-P2.54-V-M~HDR-TH_15P-P2.54-M-LI-1X15P~FMY4.step
SOP-16_L10.0-W3.9-P1.27-LS6.0-BL~SOP-16_L9.9-W3.9-H1.5-LS6.0-P1.27~FMY4.step
SMB_L4.5-W3.6-LS5.3-BI~SMB_L4.5-W3.6-LS5.3-RD~FMY4.step x 9
SOIC-16_L9.9-W3.9-P1.27-LS6.0-BL-1~SOIC-16_L9.9-W3.9-H1.8-LS6.0-P1.27-EP13~FMY4.step
Board~FMY4.step
BASE
IN8~LED0805-R-RD~LED0805-RD~uFa5.step x 8
R0805~R0805_L2.0-W1.3-H0.6~uFa5.step x 14
C0805~C0805_L2.0-W1.3-H1.3~uFa5.step
CONN-TH_2P-P5.08_WJ2EDGRC-5.08-2P~CONN-TH_2P-L12.0-W12.2-H8.3-P5.08~uFa5.step
HDR-TH_15P-P2.54-V-M~HDR-TH_15P-P2.54-M-LI-1X15P~uFa5.step
MSOP-10_L3.0-W3.0-P0.50-LS5.0-BL~MSOP-10_L3.0-W3.0-H1.1-LS5.0-P0.50~uFa5.step
OLED-TH_L27.8-W27.2-P2.54_C9900033791~OLED-TH_L27.8-W27.2-P2.54_C9900033791~uFa5.step
CONN-TH_3P-P5.08_WJ2EDGRC-5.08-3P~CONN-TH_WJ5.08-WI-3P-4~uFa5.step
SW-TH_5.8ZSPT~SW-TH_5.8ZSPT~uFa5.step x 8
Board~uFa5.step
DISTANZIALE INTERNO x 4
DISTANZIALE SOPRA x 4
COPERCHIO
SUPPORTO
BOTTONE INPUT
BOTTONE OK

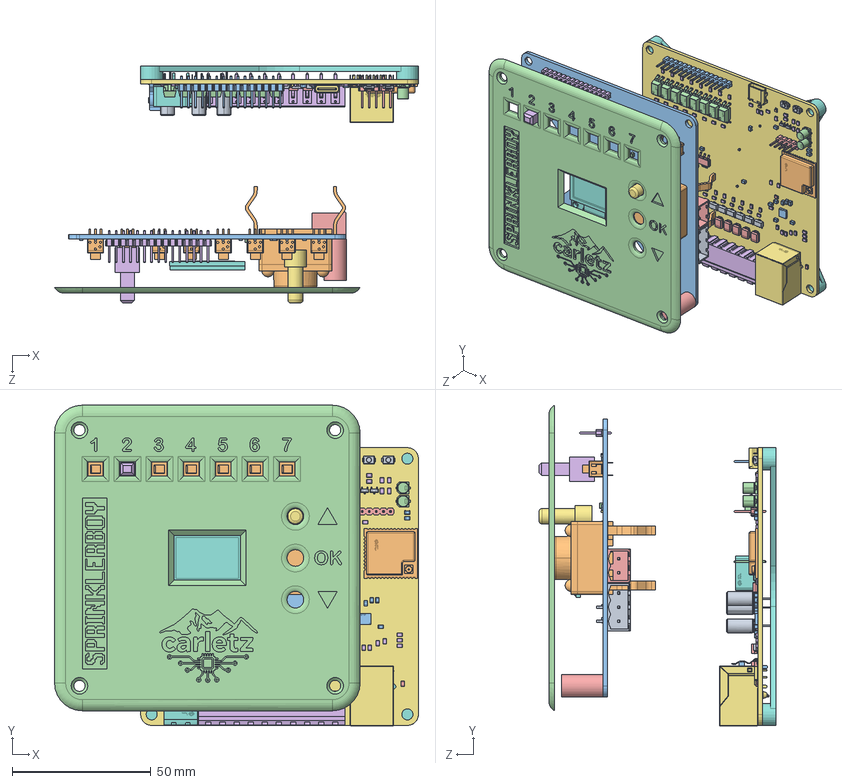
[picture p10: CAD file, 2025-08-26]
3D Model/Prato/SBprato.SLDASM
131.0 x 115.4 x 85.4 mm
CAP-TH_BD5.0-P2.00-D0.8-FD~CAP-TH_BD5.0-P2.00-D0.5-FD-A~FMY4.step x 3
SMA_L4.3-W2.5-LS5.0-RD~SMA_L4.3-W2.5-LS5.0-RD-1~FMY4.step
FUSE-TH_5X20RHOSFUSECLIP-SEAT~FUSE-TH_5X20~FMY4.step x 2
HDR-TH_3P-P2.54-V-M-1~HDR-M-2.54_1x3~FMY4.step
L0805~R0805_L2.0-W1.3-H0.6~FMY4.step x 2
R0805_NEW~R0805_L2.0-W1.3-H0.6~FMY4.step x 56
RJ45-TH_HR911105A~RJ45-TH_HR911105A~FMY4.step
IND-SMD_L12.3-W12.3_SMDRI127~SMD-PIND_L12.5-W12.5-H8.0~FMY4.step
SOT-23-3_L2.9-W1.3-P1.90-LS2.4-BR~SOT-23-3P_L2.9-W1.3-H1.0-LS2.4-P0.95~FMY4.step x 2
WIFI-SMD_ESP32-WROOM-32UE~WIFI-SMD_L19.2-18.0-H3.2-ESP32-WROOM-32UE~FMY4.step
QFN-24_L4.0-W4.0-P0.50-TL-EP2.5~VFQFN-24_L4.0-W4.0-P0.50-TL-EP2.1~FMY4.step
SOP-4_L6.4-W4.6-P2.54-LS10.2-BL~SOP-4_L6.5-W4.6-H4.5-P2.54-LS10.2-TL~FMY4.step x 8
SOT-223-4_L6.5-W3.5-P2.30-LS7.0-BR~SOT-223-4P_L6.5-W3.5-H1.6-LS7.0-P2.30~FMY4.step
SMA_L4.5-W2.7-LS5.1-RD~SMA_L4.5-W2.7-LS5.1-RD~FMY4.step
TSSOP-16_L5.0-W4.4-P0.65-LS6.4-BL~TSSOP-16_L5.0-W4.4-H1.0-LS6.4-P0.65~FMY4.step
SOIC-8_L5.0-W4.0-P1.27-LS6.0-BL~SOIC-8_L4.9-W3.9-H1.7-LS6.0-P1.27~FMY4.step
SOT-89-3_L4.5-W2.5-P1.50-LS4.2-BR~SOT-89-3_L4.3-W2.5-H1.6-LS4.1-P1.50~FMY4.step x 8
LED0805-R-RD~LED0805-RD_RED_XL-2012SURC-FJ~FMY4.step
C0805~C0805_L2.0-W1.3-H1.3~FMY4.step x 16
CAP-SMD_BD4.0-L4.3-W4.3-LS5.1-FD~CAP-SMD_BD4.0-L4.3-W4.3-LS5.1-FD~FMY4.step x 2
HDR-TH_5P-P2.54-V-M~HDR-TH_5P-P2.54-M-LI-1X5P~FMY4.step
CONN-TH_10P-P5.08_WJ2EDGRC-5.08-10P~CONN-TH_10P-P5.08_WJ2EDGRC-5.08-10P~FMY4.step
USB-C-SMD_TYPE-C-6PIN-2MD-073~USB-C-SMD_TYPE-C-6PIN-2MD-073~FMY4.step
CONN-TH_2P-P5.08_WJ2EDGRC-5.08-2P~CONN-TH_2P-L12.0-W12.2-H8.3-P5.08~FMY4.step
SW-SMD_L3.9-W3.0-P4.45~SW-SMD_L3.9-W2.9-H2.0-LS4.8~FMY4.step x 2
SOT-553-5_L1.6-W1.2-P0.50-LS1.6-TL-1~SOT-553-5_L1.6-W1.2-P0.50-LS1.6-TL-1~FMY4.step
HDR-TH_15P-P2.54-V-M~HDR-TH_15P-P2.54-M-LI-1X15P~FMY4.step
SOP-16_L10.0-W3.9-P1.27-LS6.0-BL~SOP-16_L9.9-W3.9-H1.5-LS6.0-P1.27~FMY4.step
SMB_L4.5-W3.6-LS5.3-BI~SMB_L4.5-W3.6-LS5.3-RD~FMY4.step x 9
SOIC-16_L9.9-W3.9-P1.27-LS6.0-BL-1~SOIC-16_L9.9-W3.9-H1.8-LS6.0-P1.27-EP13~FMY4.step
Board~FMY4.step
BASE SBPrato
IN8~LED0805-R-RD~LED0805-RD~uFa5.step x 8
R0805~R0805_L2.0-W1.3-H0.6~uFa5.step x 14
C0805~C0805_L2.0-W1.3-H1.3~uFa5.step
CONN-TH_2P-P5.08_WJ2EDGRC-5.08-2P~CONN-TH_2P-L12.0-W12.2-H8.3-P5.08~uFa5.step
HDR-TH_15P-P2.54-V-M~HDR-TH_15P-P2.54-M-LI-1X15P~uFa5.step
MSOP-10_L3.0-W3.0-P0.50-LS5.0-BL~MSOP-10_L3.0-W3.0-H1.1-LS5.0-P0.50~uFa5.step
OLED-TH_L27.8-W27.2-P2.54_C9900033791~OLED-TH_L27.8-W27.2-P2.54_C9900033791~uFa5.step
CONN-TH_3P-P5.08_WJ2EDGRC-5.08-3P~CONN-TH_WJ5.08-WI-3P-4~uFa5.step
SW-TH_5.8ZSPT~SW-TH_5.8ZSPT~uFa5.step x 8
Board~uFa5.step
COVER ESTERNA
DISTANZIALE FRONTE
BOTTONE VALVOLA
BOTTONE OK

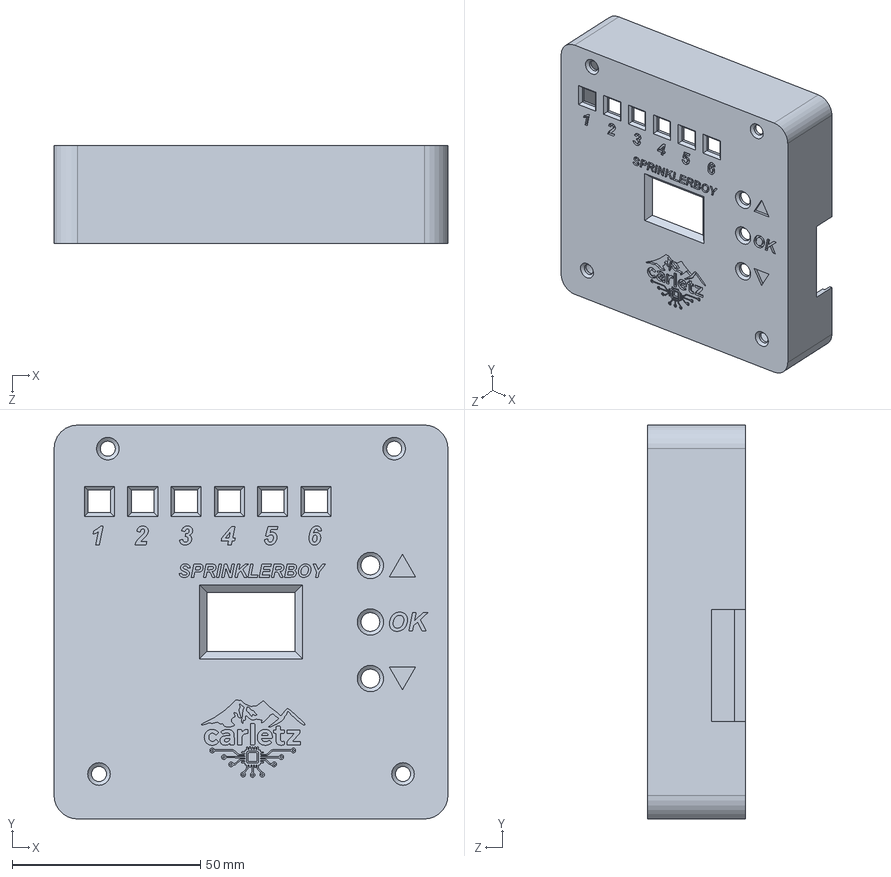
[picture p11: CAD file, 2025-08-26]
3D Model/COPERCHIO.SLDPRT
104.6 x 104.6 x 26.1 mm

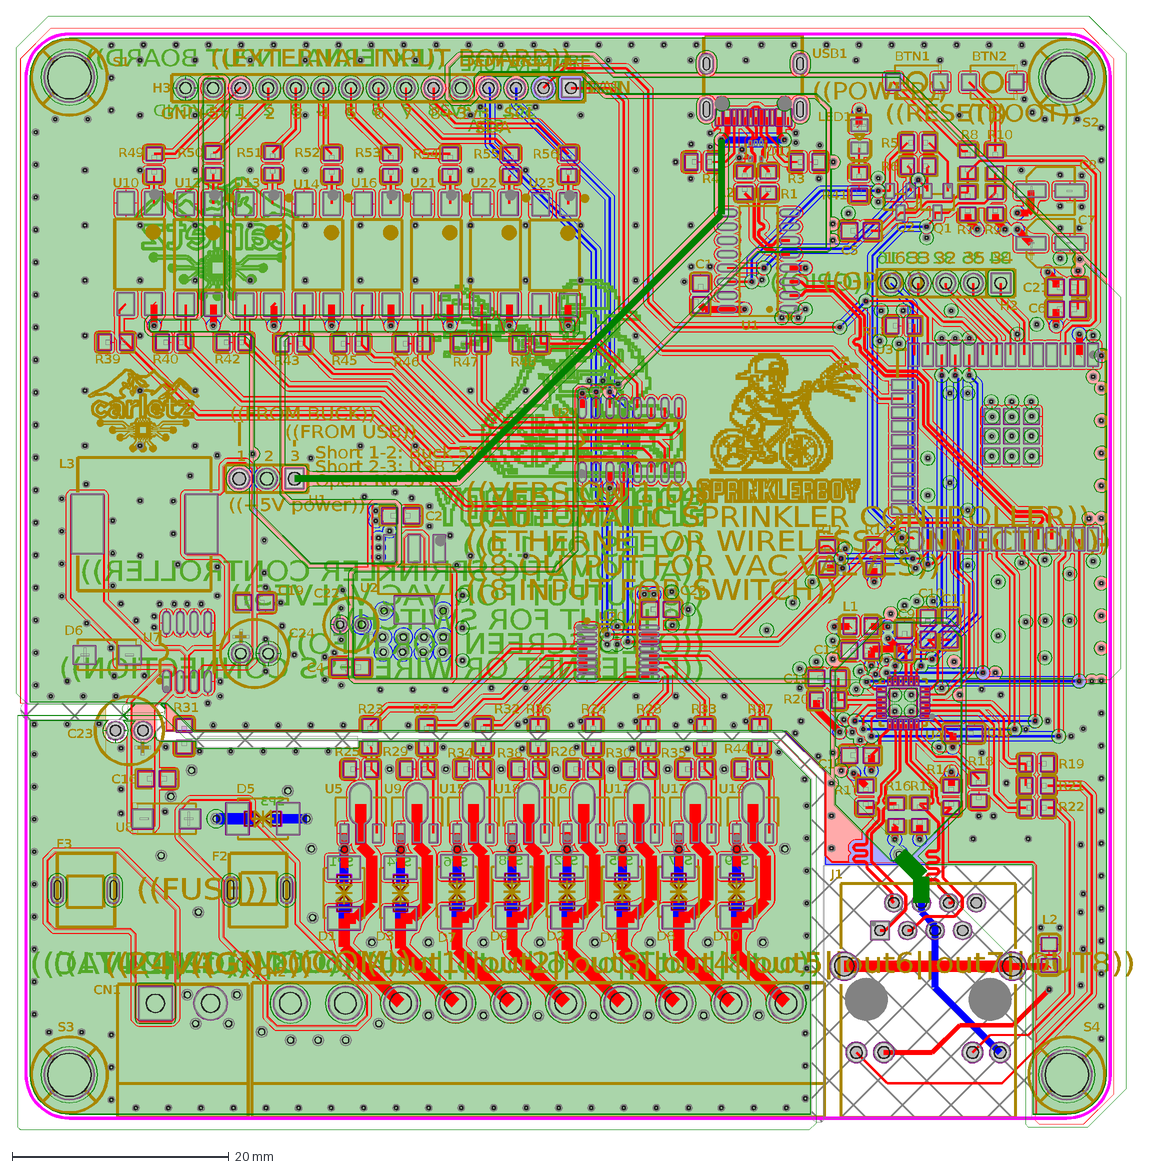
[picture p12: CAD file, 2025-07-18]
Hardware/DXF_SprinklerBoy_2025-07-18_AutoCAD2007.dxf
((VERSION 1.0))
((AUTOMATIC SPRINKLER CONTROLLER))
((8 OUTPUT FOR VAC VALVES))
((8 INPUT FOR SWITCH))
((OLED SCREEN FOR INFO))
((ETHERNET OR WIRELESS CONNECTION))
((GPIO))
16
33
32
35
34
((GND))
((24VAC))
((COM))
((out8||out7||out6||out5||out4||out3||out2||OUT1))
GND
+5V
1
2
3
4
5
6
7
8
((EXTERNAL INPUT BOARD))
+3V3
SDA
SCL
TEMPERATURE
RAIN
SP1
SP4
SP6
SP8
SP3
SP2
SP5
SP7
SP9
((out1||out2||out3||out4||out5||out6||out7||OUT8))
((FUSE))
((+5V power))
((FROM BUCK))
((FROM USB))
((POWER))
((RESET))
((BOOT))
Short 1-2: Buck 5V
Short 2-3: USB 5V
Open: No 5V!
D1
D3
D7
D9
D5
D6
F3
F2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

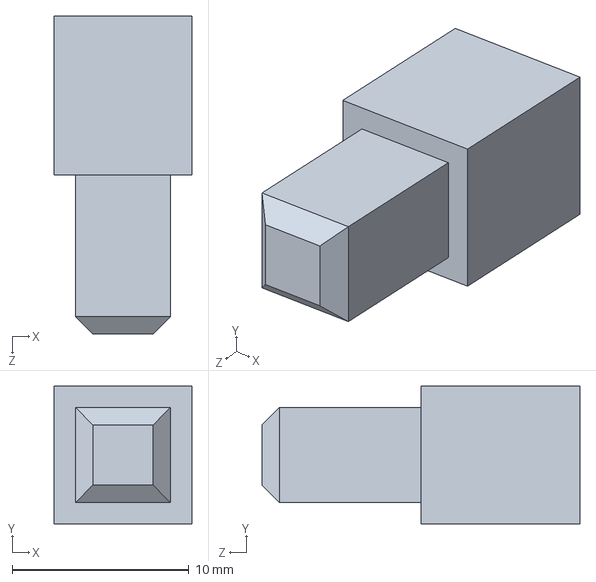
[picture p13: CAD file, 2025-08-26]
3D Model/BOTTONE INPUT.SLDPRT
7.80 x 7.80 x 18.0 mm

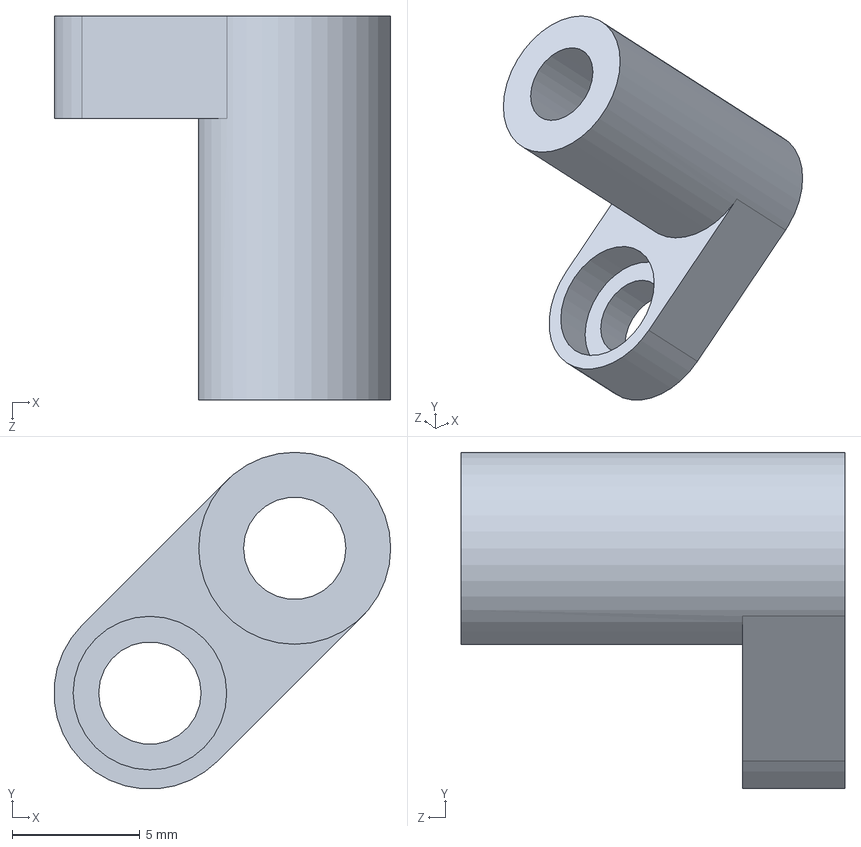
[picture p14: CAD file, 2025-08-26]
3D Model/DISTANZIALE SOPRA.SLDPRT
13.1 x 13.1 x 15.0 mm

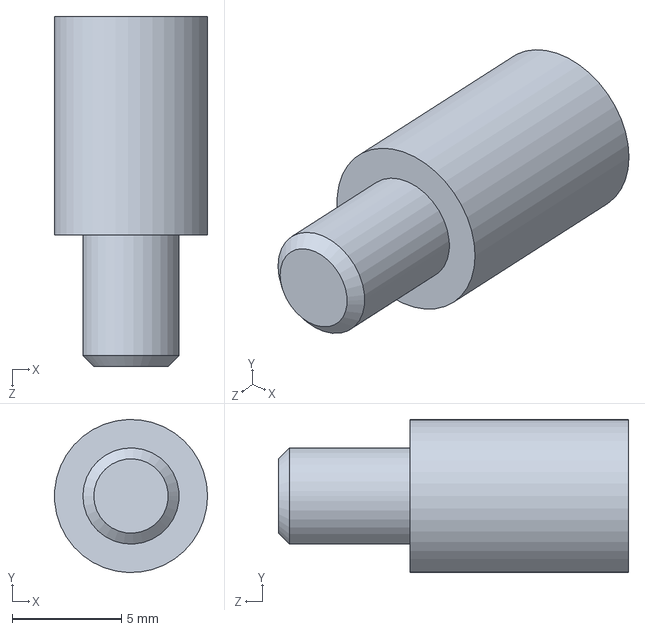
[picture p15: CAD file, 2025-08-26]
3D Model/BOTTONE OK.SLDPRT
7.00 x 6.99 x 16.0 mm

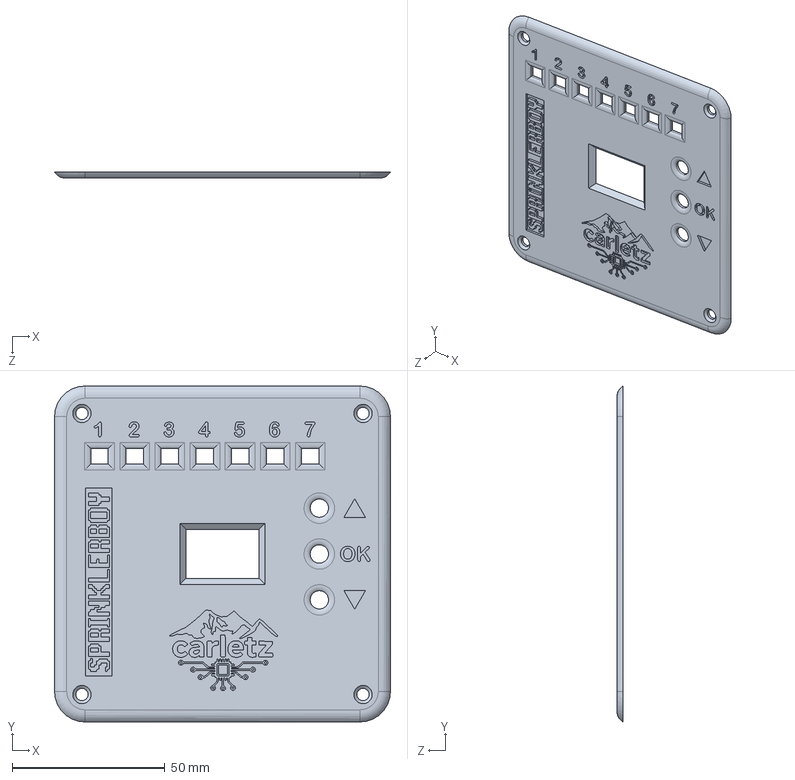
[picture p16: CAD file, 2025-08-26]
3D Model/Prato/COVER ESTERNA.SLDPRT
110.0 x 110.0 x 2.00 mm

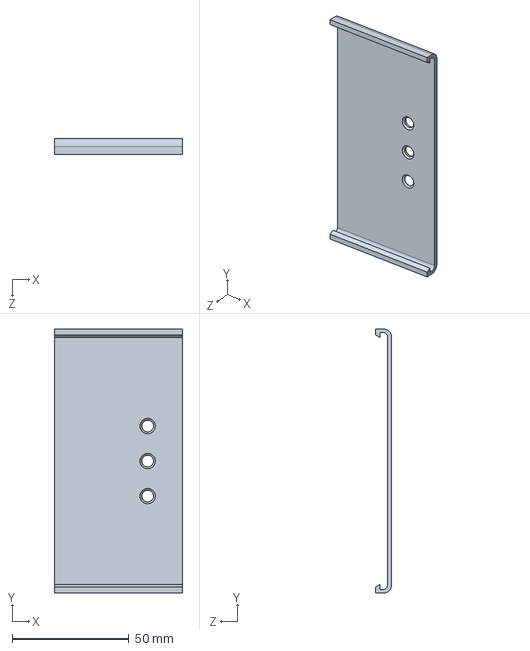
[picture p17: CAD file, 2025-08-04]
3D Model/SUPPORTO.SLDPRT
55.0 x 113.1 x 7.00 mm

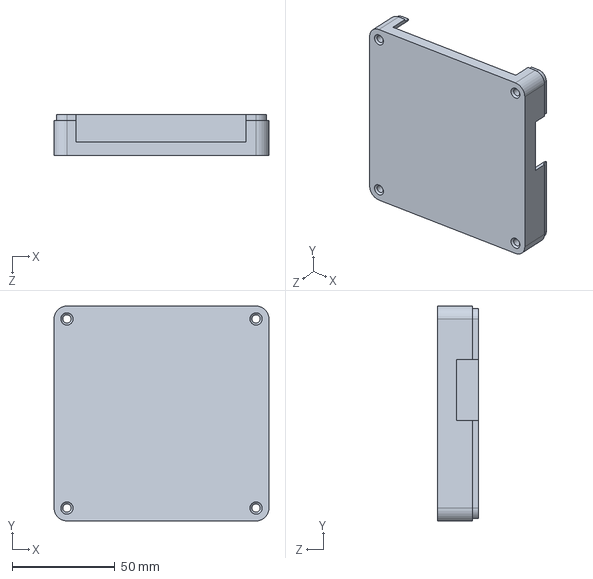
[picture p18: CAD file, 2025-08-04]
3D Model/BASE.SLDPRT
104.6 x 104.6 x 20.0 mm

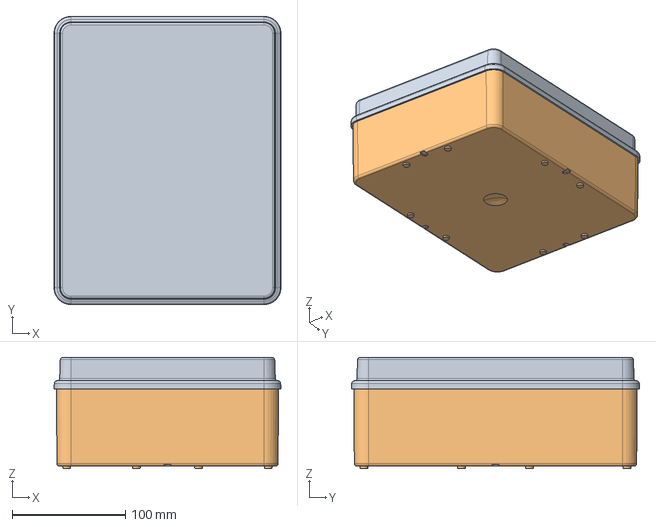
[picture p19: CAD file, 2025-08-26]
3D Model/Prato/44ce240x190plcb.stp
200.2 x 254.2 x 98.0 mm
55910277B4X1_COPERCHIO_BASSO
55910681A2X3_FONDO_CASSETTA_LIS

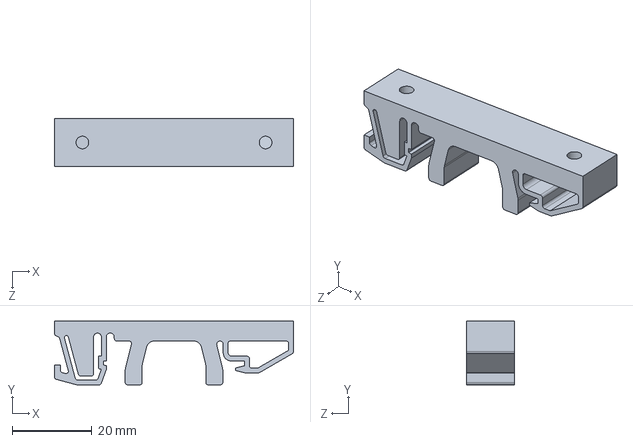
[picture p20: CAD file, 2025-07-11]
3D Model/dins_clip.sldprt
60.0 x 16.0 x 12.0 mm

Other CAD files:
3D Model/Prato/BOTTONE OK.SLDPRT
3D Model/Prato/BASE SBPrato.SLDPRT
3D Model/Prato/DISTANZIALE FRONTE.SLDPRT
3D Model/Prato/LEGNO.SLDPRT
3D Model/DISTANZIALE INTERNO.SLDPRT
3D Model/Prato/BOTTONE VALVOLA.SLDPRT
3D Model/BASE.STL
3D Model/BOTTONE INPUT.STL
3D Model/BOTTONE OK.STL
3D Model/COPERCHIO.STL
3D Model/DISTANZIALE INTERNO.STL
3D Model/DISTANZIALE SOPRA.STL
3D Model/Prato/3D_InputBoard_2025-06-05.step
3D Model/Prato/BASE SBPrato.STL
3D Model/Prato/BOTTONE OK.STL
3D Model/Prato/BOTTONE VALVOLA.STL
3D Model/Prato/COVER ESTERNA.STL
3D Model/Prato/DISTANZIALE FRONTE.STL
3D Model/SUPPORTO.STL

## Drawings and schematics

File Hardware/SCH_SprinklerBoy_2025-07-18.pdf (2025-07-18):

# USB Board Power supply

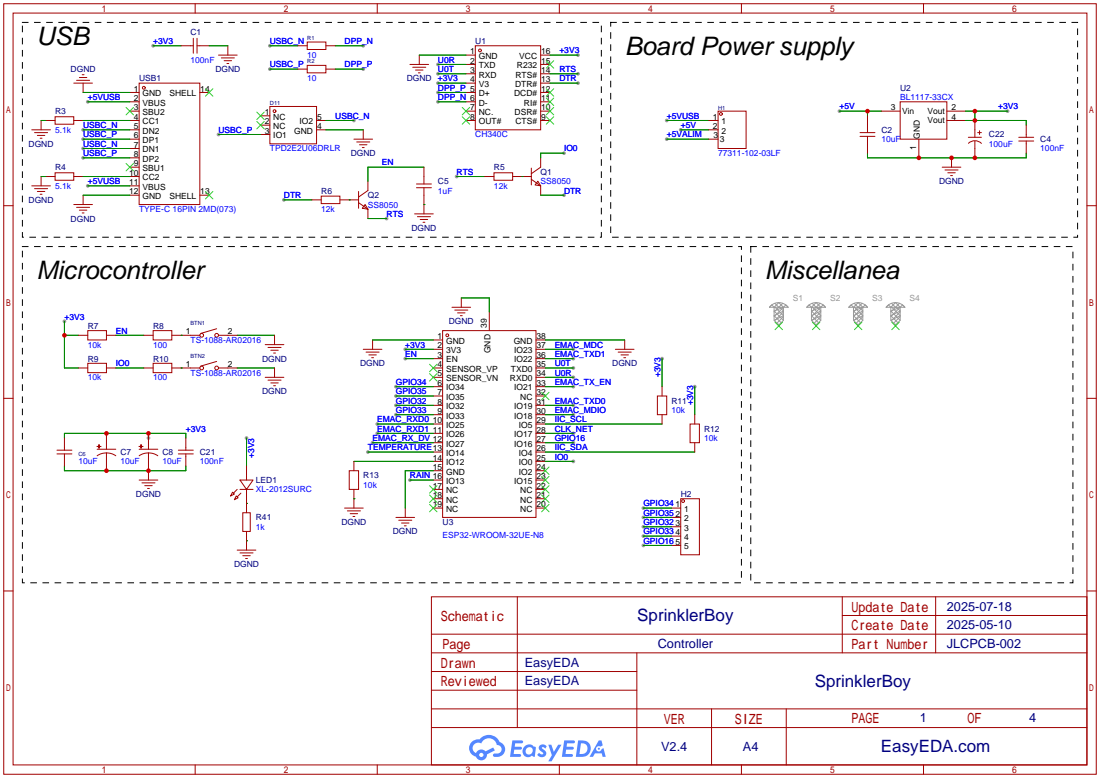
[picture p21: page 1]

DSR# 10 RI# 11 DCD# 12 DTR# 13 RTS# 14 R232 15 VCC 16

# DGND ⁺³.3VNET

# Ethernet

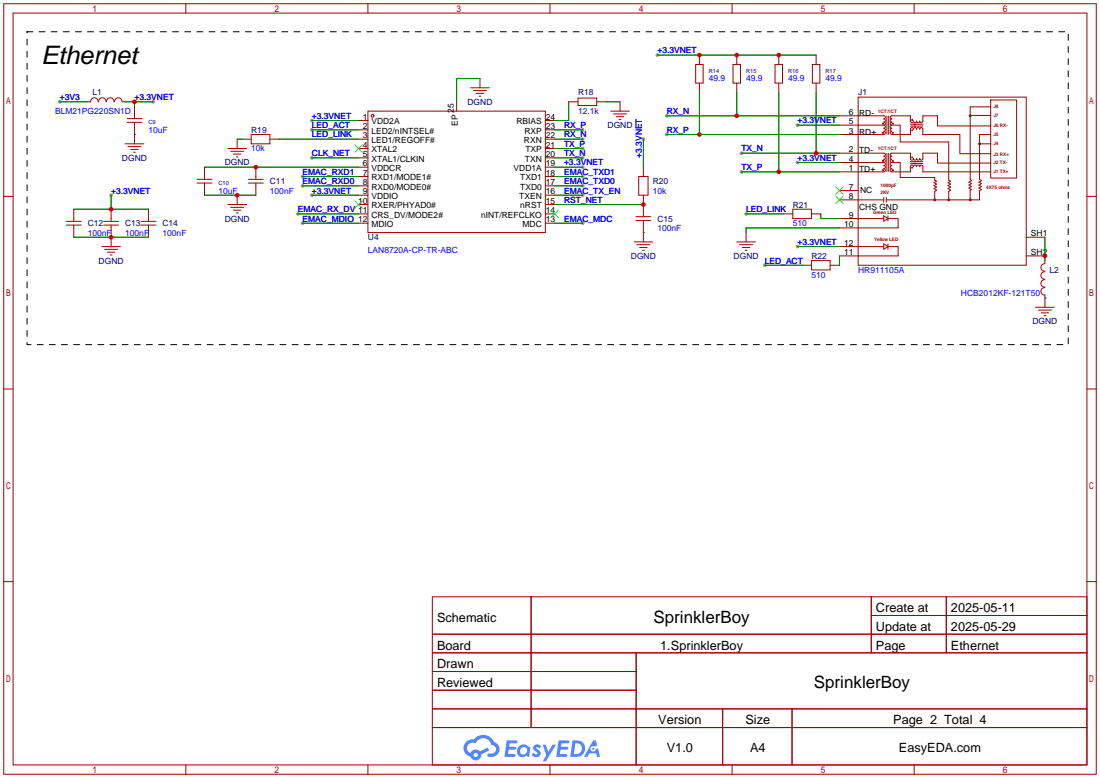
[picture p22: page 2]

Schematic | SprinklerBoy | Create at | 2025-05-11

Update at | 2025-05-29

Board | 1.SprinklerBoy | Page | Ethernet
Drawn | | SprinklerBoy
Reviewed

Version | Size | Page 2 Total 4
V1.0 | A4 | EasyEDA.com

# Sprinkler valves

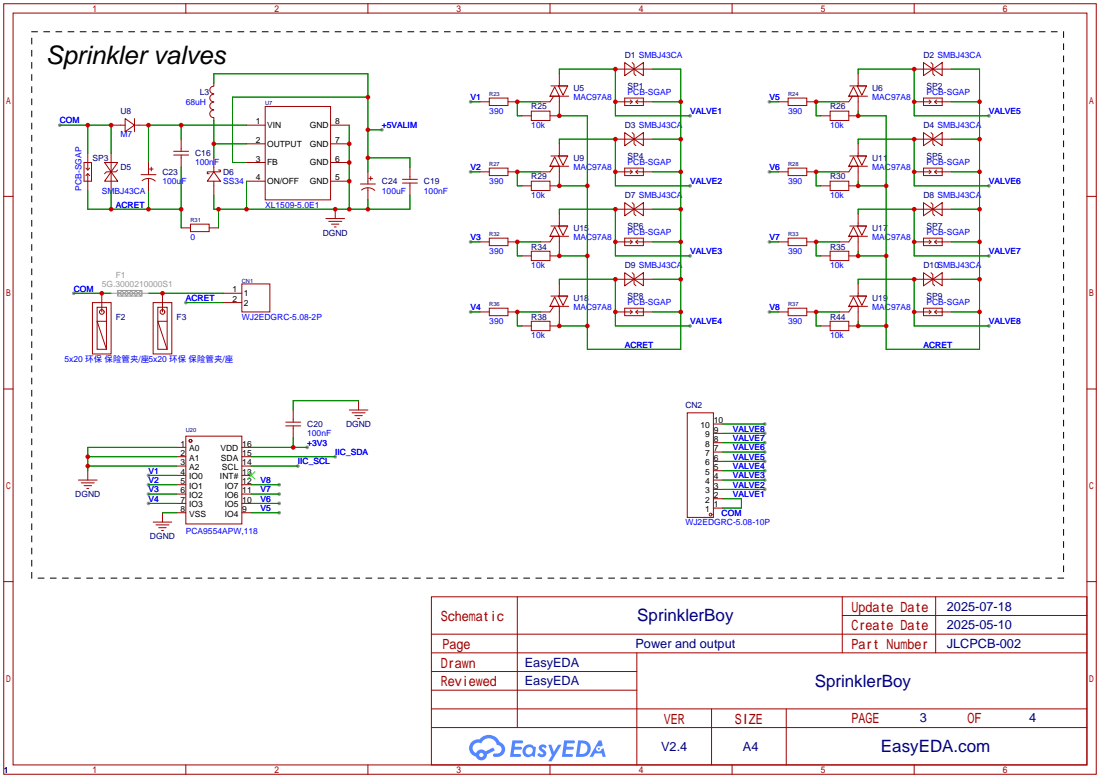
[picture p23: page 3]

# External input

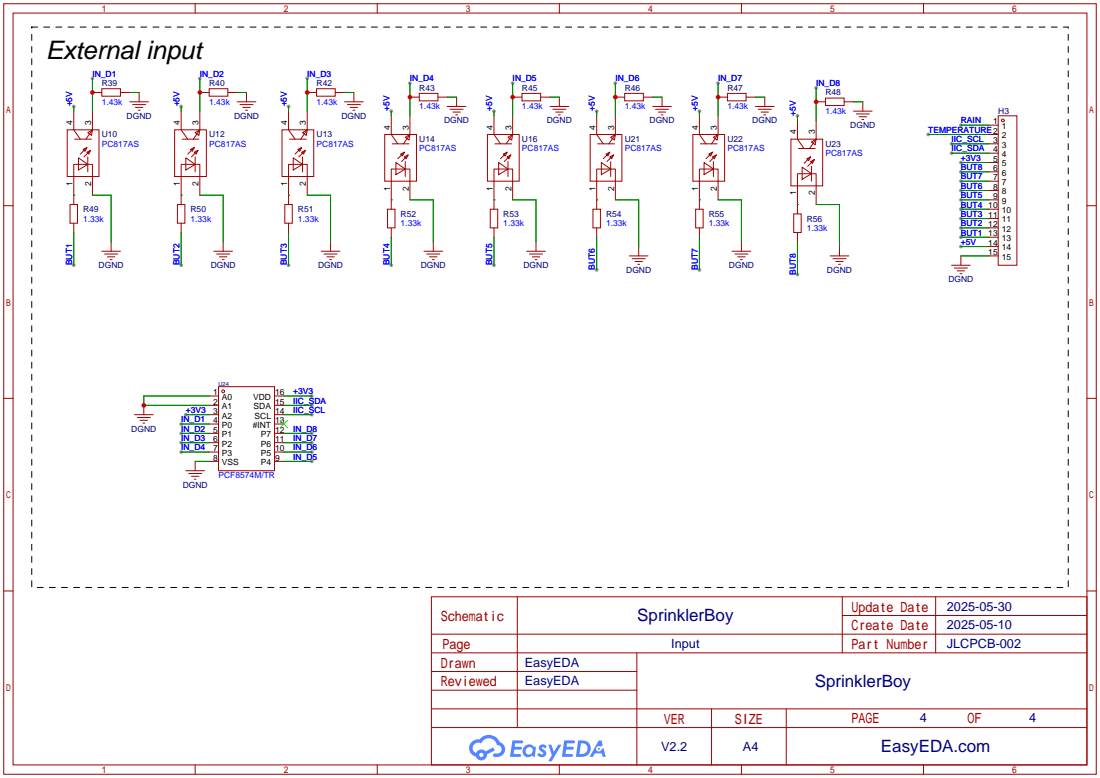
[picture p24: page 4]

P5 10 P6 11 P7 12 #INT 13 SCL 14 SDA 15 VDD 16

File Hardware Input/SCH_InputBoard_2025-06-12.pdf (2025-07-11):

# Input Board

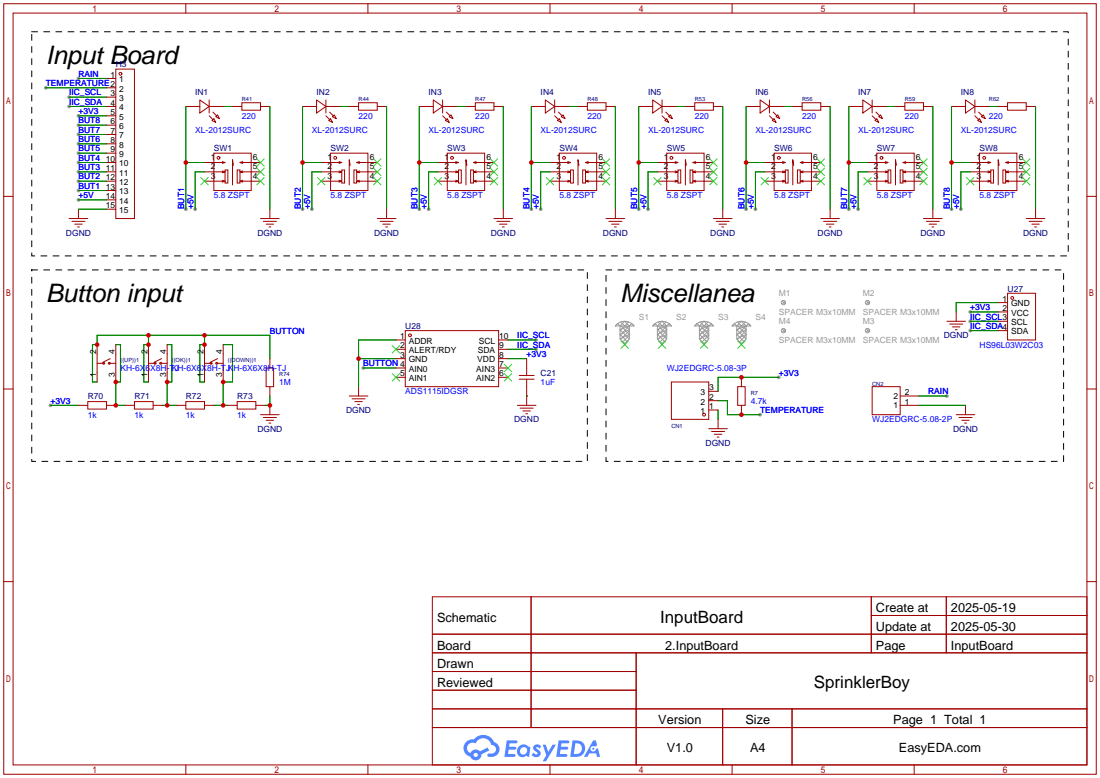
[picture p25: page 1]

Schematic | InputBoard | Create at | 2025-05-19

Update at | 2025-05-30

Board | 2.InputBoard | Page | InputBoard
Drawn | | SprinklerBoy
Reviewed

Version | Size | Page 1 Total 1
V1.0 | A4 | EasyEDA.com

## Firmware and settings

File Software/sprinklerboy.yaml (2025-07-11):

substitutions:
  # Modify variables based on your settings
  hostname: "sprinklerboy"
  devicename: SprinklerBoy

esphome:
  name: $hostname
  friendly_name: $devicename

esp32:
  board: esp32dev

logger:

ota:
  - platform: esphome
    password: ""

web_server:
  port: 80

i2c:
  sda: 4
  scl: 5
  scan: true
  id: bus_a

ethernet:
  type: LAN8720
  mdc_pin: GPIO23
  mdio_pin: GPIO18
  clk_mode: GPIO17_OUT
  phy_addr: 0
  power_pin: GPIO12
  manual_ip:
    static_ip: 192.168.1.47
    gateway: 192.168.1.1
    subnet: 255.255.255.0

mqtt:
  broker: 192.168.1.42
  discovery: true
  birth_message:
    topic: $devicename/status
    payload: online
  will_message:
    topic: $devicename/status
    payload: offline

  on_message:
    - topic: "$devicename/Valve 1/command"
      then:
        - lambda: |-
            if (x == "ON") id(valve_1).turn_on();
            else if (x == "OFF") id(valve_1).turn_off();
    - topic: "$devicename/Valve 2/command"
      then:
        - lambda: |-
            if (x == "ON") id(valve_2).turn_on();
            else if (x == "OFF") id(valve_2).turn_off();
    - topic: "$devicename/Valve 3/command"
      then:
        - lambda: |-
            if (x == "ON") id(valve_3).turn_on();
            else if (x == "OFF") id(valve_3).turn_off();
    - topic: "$devicename/Valve 4/command"
      then:
        - lambda: |-
            if (x == "ON") id(valve_4).turn_on();
            else if (x == "OFF") id(valve_4).turn_off();
    - topic: "$devicename/Valve 5/command"
      then:
        - lambda: |-
            if (x == "ON") id(valve_5).turn_on();
            else if (x == "OFF") id(valve_5).turn_off();
    - topic: "$devicename/Valve 6/command"
      then:
        - lambda: |-
            if (x == "ON") id(valve_6).turn_on();
            else if (x == "OFF") id(valve_6).turn_off();
    - topic: "$devicename/Valve 7/command"
      then:
        - lambda: |-
            if (x == "ON") id(valve_7).turn_on();
            else if (x == "OFF") id(valve_7).turn_off();
    - topic: "$devicename/Valve 8/command"
      then:
        - lambda: |-
            if (x == "ON") id(valve_8).turn_on();
            else if (x == "OFF") id(valve_8).turn_off();
    - topic: "$devicename/Valve 1/enable"
      then:
        - lambda: |-
            id(enable_valve_1) = (x == "ON");
            ESP_LOGI("mqtt", "Valve 1 enable set to %s", x.c_str());
    - topic: "$devicename/Valve 2/enable"
      then:
        - lambda: |-
            id(enable_valve_2) = (x == "ON");
            ESP_LOGI("mqtt", "Valve 2 enable set to %s", x.c_str());
    - topic: "$devicename/Valve 3/enable"
      then:
        - lambda: |-
            id(enable_valve_3) = (x == "ON");
            ESP_LOGI("mqtt", "Valve 3 enable set to %s", x.c_str());
    - topic: "$devicename/Valve 4/enable"
      then:
        - lambda: |-
            id(enable_valve_4) = (x == "ON");
            ESP_LOGI("mqtt", "Valve 4 enable set to %s", x.c_str());
    - topic: "$devicename/Valve 5/enable"
      then:
        - lambda: |-
            id(enable_valve_5) = (x == "ON");
            ESP_LOGI("mqtt", "Valve 5 enable set to %s", x.c_str());
    - topic: "$devicename/Valve 6/enable"
      then:
        - lambda: |-
            id(enable_valve_6) = (x == "ON");
            ESP_LOGI("mqtt", "Valve 6 enable set to %s", x.c_str());
    - topic: "$devicename/Valve 7/enable"
      then:
        - lambda: |-
            id(enable_valve_7) = (x == "ON");
            ESP_LOGI("mqtt", "Valve 7 enable set to %s", x.c_str());
    - topic: "$devicename/Valve 8/enable"
      then:
        - lambda: |-
            id(enable_valve_8) = (x == "ON");
            ESP_LOGI("mqtt", "Valve 8 enable set to %s", x.c_str());

    - topic: "$devicename/All Valves/enable"
      then:
        - lambda: |-
            bool enable = (x == "ON");
            id(enable_valve_1) = enable;
            id(enable_valve_2) = enable;
            id(enable_valve_3) = enable;
            id(enable_valve_4) = enable;
            id(enable_valve_5) = enable;
            id(enable_valve_6) = enable;
            id(enable_valve_7) = enable;
            id(enable_valve_8) = enable;
            ESP_LOGI("mqtt", "All valves enable set to %s", x.c_str());
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
